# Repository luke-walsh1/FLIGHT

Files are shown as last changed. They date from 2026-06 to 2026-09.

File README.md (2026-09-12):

<p align="center">

</p>

## FLIGHT

FLIGHT is a custom, high-performance rocket flight computer designed around a Raspberry Pi Pico (RP2040) to track, log, and deploy parachutes using a servo.

## Disclaimer
### The provided code is tested and working with the hardware; however, the servo and arm button controls can be customized to suit your specific needs and are not implimented in the code:)

---

rasppico altimiter 1 7



---

## Features

* Core Processing: Raspberry Pi Pico running custom data-logging, and control scripts.

* Integrated Sensors (GY-91): Combines an IMU (accelerometer/gyroscope) to measure high-G launch forces (± 16g) and orientation, alongside a precision barometer (BMP280) to calculate real-time altitude changes.

* Recovery: Dedicated PWM outputs to trigger a servo mechanism for physical parachute deployment at apogee or however you wish to use it. not implimented in code, challange for yourself :)

* Power & Protection Circuitry: Integrated TP4056 LiPo charging network backed by a comprehensive safety protection block (DW01A controller + FS8205A dual-MOSFET switch) to safely manage battery current and prevent over-discharge.

* Voltage Regulation (MT3608): A  DC-DC boost converter circuit to cleanly step up battery power to a stable $5\text{V}$ line for the onboard servo control.

  rasppico altimiter 1 7 back



---

## Mechanical & Layout Design

* Developed on a dual-layer PCB with a massive Ground Plane optimized for low electrical noise and high signal integrity.
  
* Designed with wide, heavy-current traces ($0.8\text{mm} - 1.0\text{mm}$) on the critical power highway loops (+BATT and -BATT) to safely absorb massive amp spikes when the deployment servos actuate.
  
* Custom aerospace graphics and visual infographics directly on the silkscreen layer.

<p align="center">
 
</p>

# DATA

The goal is to log data. FLIGHT saves data in a format that looks like this:



---

These numbers by themselves arent that helpfull however with the help of a python program we can graph this data and mark the max altitude and other data points.

---



---

Included in the files is also a 3d printable bracket to mount flight to your rocket,
step file for your own needs.
M3 countersunk screw holes for mounting to rocket.

More on my YouTube and Stardance Profile:

https://stardance.hackclub.com/projects/18720

https://www.youtube.com/watch?v=rl3e3K6eBTs

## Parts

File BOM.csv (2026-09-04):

ALL CAPS AND RESISTORS ARE SMD 0805 SIZE
Capacitors |  | Rough price in usd
c1 | 0.1uf
c2 | 10uf
c3 | 47uf
c4 | 22uf
c5 | 22uf
c6 | 10uf
Resistors
R1 | 1K
R2 | 1K
R3 | 1K
R4 | 1K
R5 | 100 ohm
R6 | 16K
R7 | 2.2K
IC'S | Footprint
TP4056 | SOP8 | 1
FS8205A | SOP65P640X120-8N | This and dw01a for
DW01A | SOT-23-6 | 4.67
MT3608 | SOT-23-6 | 2
2.54mm PIN HEADERS
1x2 | 2 | Kit for 5.34
1x3 | 1
1x6 | 2
1x8 | 1
Diodes
SS34 | 1
0805 LED | 2
Inductors
22uH | 10x10x4
Connectors
jts tht 1x2 2.0mm horizontal |  | 4.74
other items
Raspberry Pi Pico |  | 6.6
Micro SD card breakout |  | 2
GY-91 Breakout |  | 10.6

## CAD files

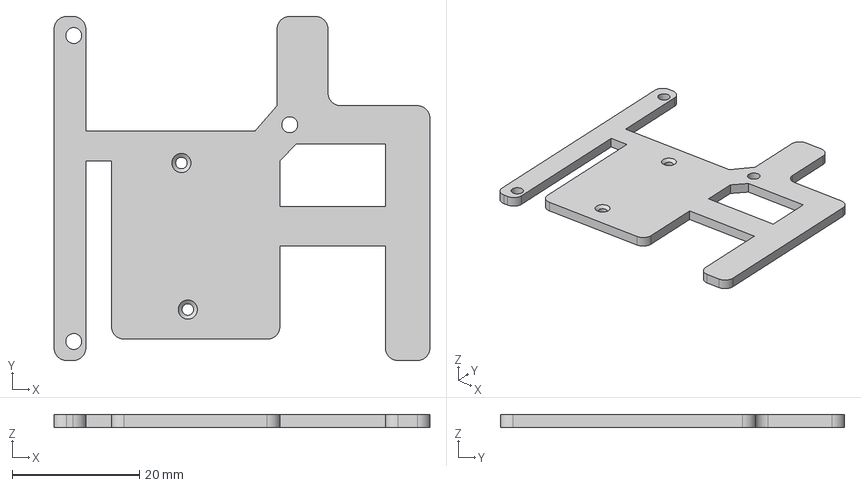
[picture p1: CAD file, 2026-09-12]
3D MODELS/MOUNT.step
59.0 x 54.0 x 2.00 mm

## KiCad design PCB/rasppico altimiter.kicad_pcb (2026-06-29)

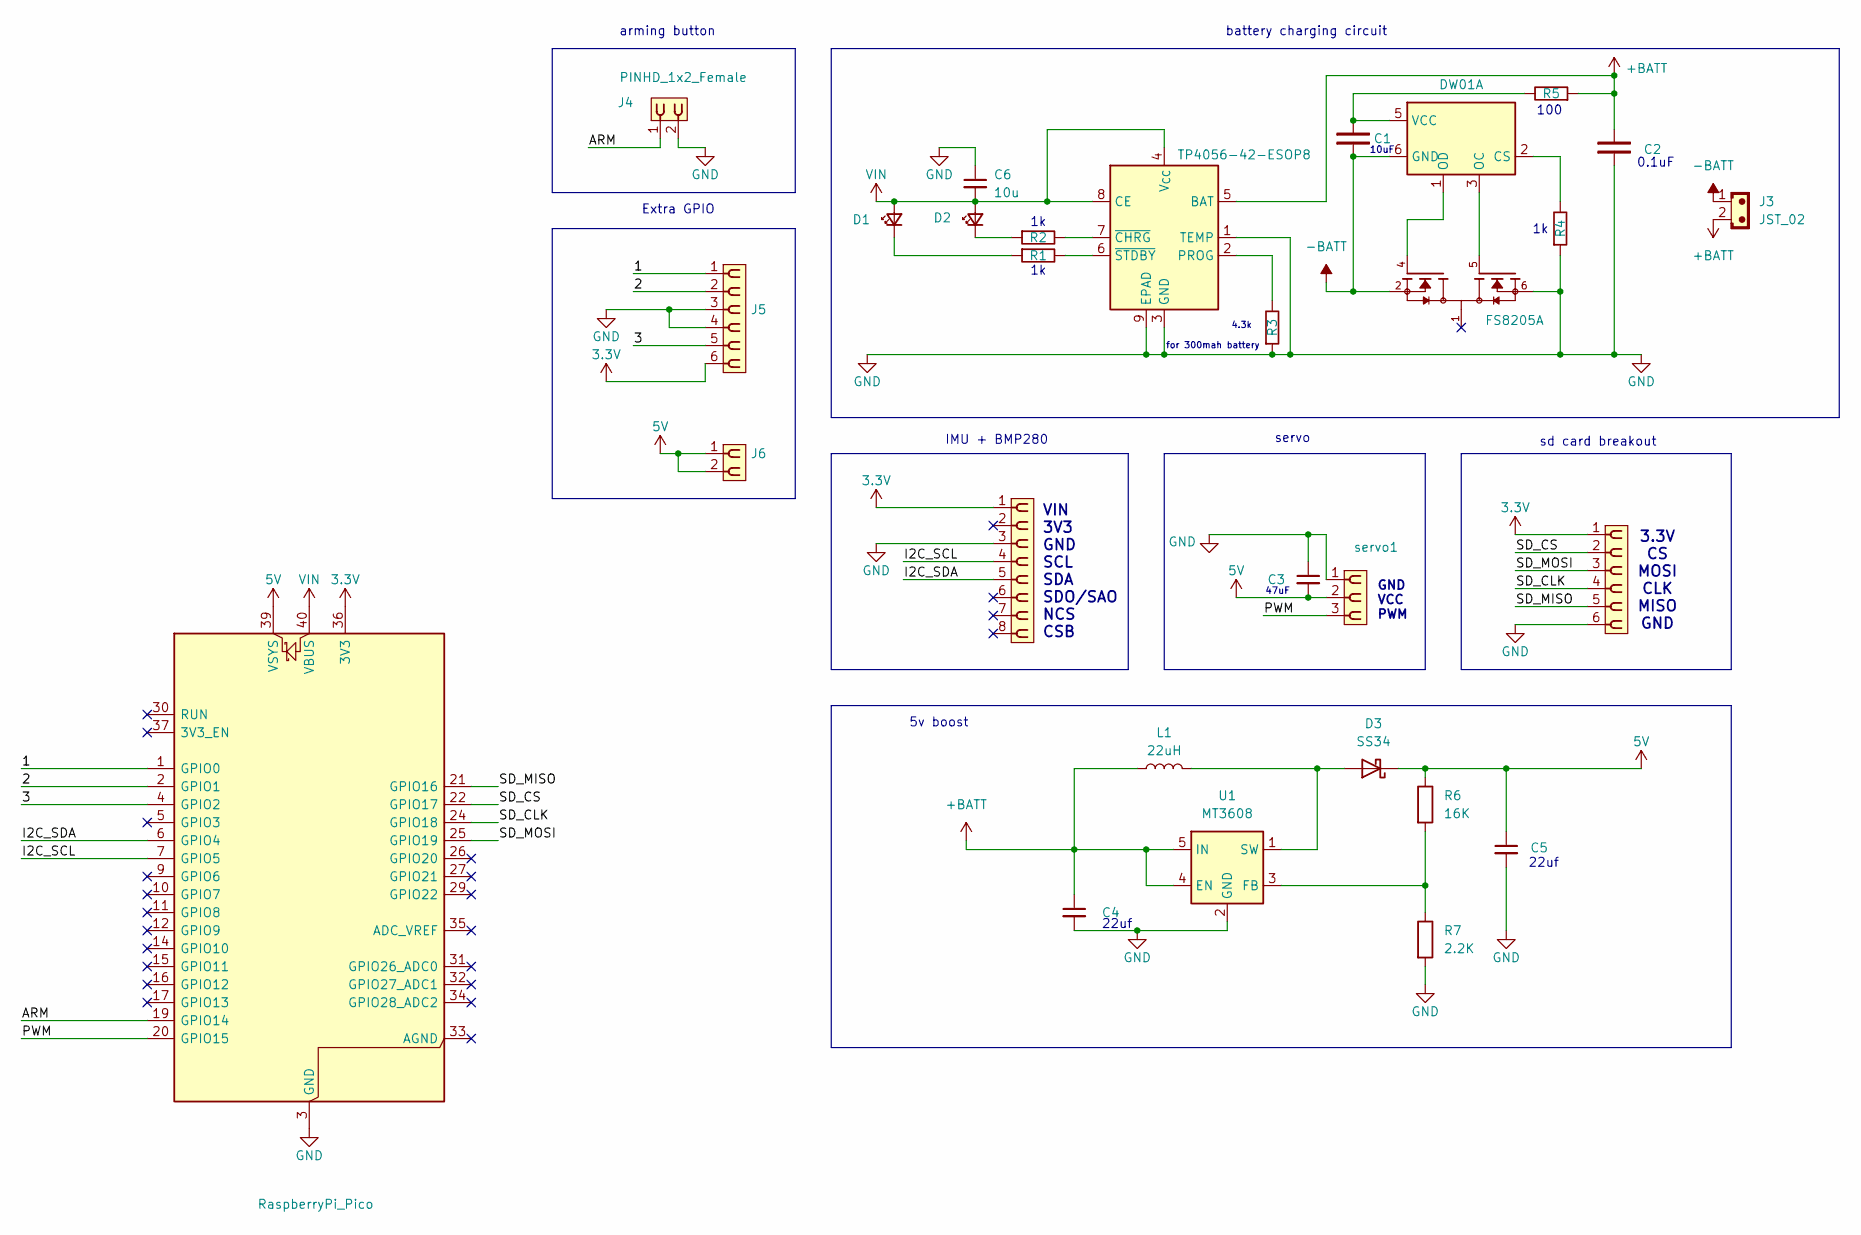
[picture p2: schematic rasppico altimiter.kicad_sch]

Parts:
A2: RaspberryPi_Pico; RaspberryPi_Pico_Common_Unspecified
C1, C2: Capacitor_NP; C_0805_2012Metric
C3, C4, C5: C; C_0805_2012Metric; Voltage 1kV; Tolerance 100%
C6: 10u; C_0603_1608Metric; Voltage 1kV; Tolerance 100%
D1, D2: LED; LED_0805_2012Metric
D3: SS34; D_SMA
J1, J5: PINHD_1x6_Female; PinSocket_1x06_P2.54mm_Vertical
J2: PINHD_1x8_Female; PinSocket_1x08_P2.54mm_Vertical
J3: JST_02; JST_PH_S2B-PH-K_1x02_P2.00mm_Horizontal
J4, J6: PINHD_1x2_Female; PinSocket_1x02_P2.54mm_Vertical
L1: 22uH; L_10.4x10.4_H4.8
Q1: FS8205A; SOP65P640X120-8N; PARTREV 1.7
R1, R2, R3, R4, R5: Resistor; R_0805_2012Metric
R6: 16K; R_0805_2012Metric
R7: 2.2K; R_0805_2012Metric
U1: MT3608; SOT-23-6
U4: TP4056-42-ESOP8; SOIC-8-1EP_3.9x4.9mm_P1.27mm_EP2.41x3.3mm_ThermalVias
U5: DW01A; SOT-23-6
servo1: PINHD_1x3_Female; PinSocket_1x03_P2.54mm_Vertical

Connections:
3.3V: A2.36 (3V3), J1.1, J2.1, J5.6
5V: A2.39 (VSYS), C3.2, C5.1, D3.1 (K), J6.1, J6.2, R6.1, servo1.2
+BATT: C2.2, C4.1, J3.2, L1.1, R5.1, U1.4 (EN), U1.5 (IN), U4.5 (BAT)
-BATT: C1.1, J3.1, Q1.2, Q1.3, U5.6 (GND)
/1: A2.1 (GPIO0), J5.1
/2: A2.2 (GPIO1), J5.2
/3: A2.4 (GPIO2), J5.5
/ARM: A2.19 (GPIO14), J4.1
/I2C_SCL: A2.7 (GPIO5), J2.4
/I2C_SDA: A2.6 (GPIO4), J2.5
/PWM: A2.20 (GPIO15), servo1.3
/SD_CLK: A2.24 (GPIO18), J1.4
/SD_CS: A2.22 (GPIO17), J1.2
/SD_MISO: A2.21 (GPIO16), J1.5
/SD_MOSI: A2.25 (GPIO19), J1.3
GND: A2.3 (GND), A2.8 (GND), A2.13 (GND), A2.18 (GND), A2.23 (GND), A2.28 (GND), A2.38 (GND), C2.1, C3.1, C4.2, C5.2, C6.1, J1.6, J2.3, J4.2, J5.3, J5.4, Q1.6, Q1.7, R3.1, R4.1, R7.2, U1.2 (GND), U4.1 (TEMP), U4.3 (GND), U4.9 (EPAD), servo1.1
unnamed: D1.1 (K), R1.1
unnamed: D2.1 (K), R2.1
unnamed: D3.2 (A), L1.2, U1.1 (SW)
unnamed: R6.2, R7.1, U1.3 (FB)
unnamed: R3.2, U4.2 (PROG)
unnamed: R2.2, U4.7 (~CHRG)
unnamed: R1.2, U4.6 (~STDBY)
unnamed: R4.2, U5.2 (CS)
unnamed: Q1.5, U5.3 (OC)
unnamed: Q1.4, U5.1 (OD)
unnamed: C1.2, R5.2, U5.5 (VCC)
VIN: A2.40 (VBUS), C6.2, D1.2 (A), D2.2 (A), U4.4 (V_{CC}), U4.8 (CE)

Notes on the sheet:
GND VCC PWM
Extra GPIO
22uf
100
battery charging circuit
VIN 3V3 GND SCL SDA SDO/SAO NCS CSB
sd card breakout
47uF
4.3k for 300mah battery
servo
0.1uF
5v boost
10uF
3.3V CS MOSI CLK MISO GND
IMU + BMP280
arming button

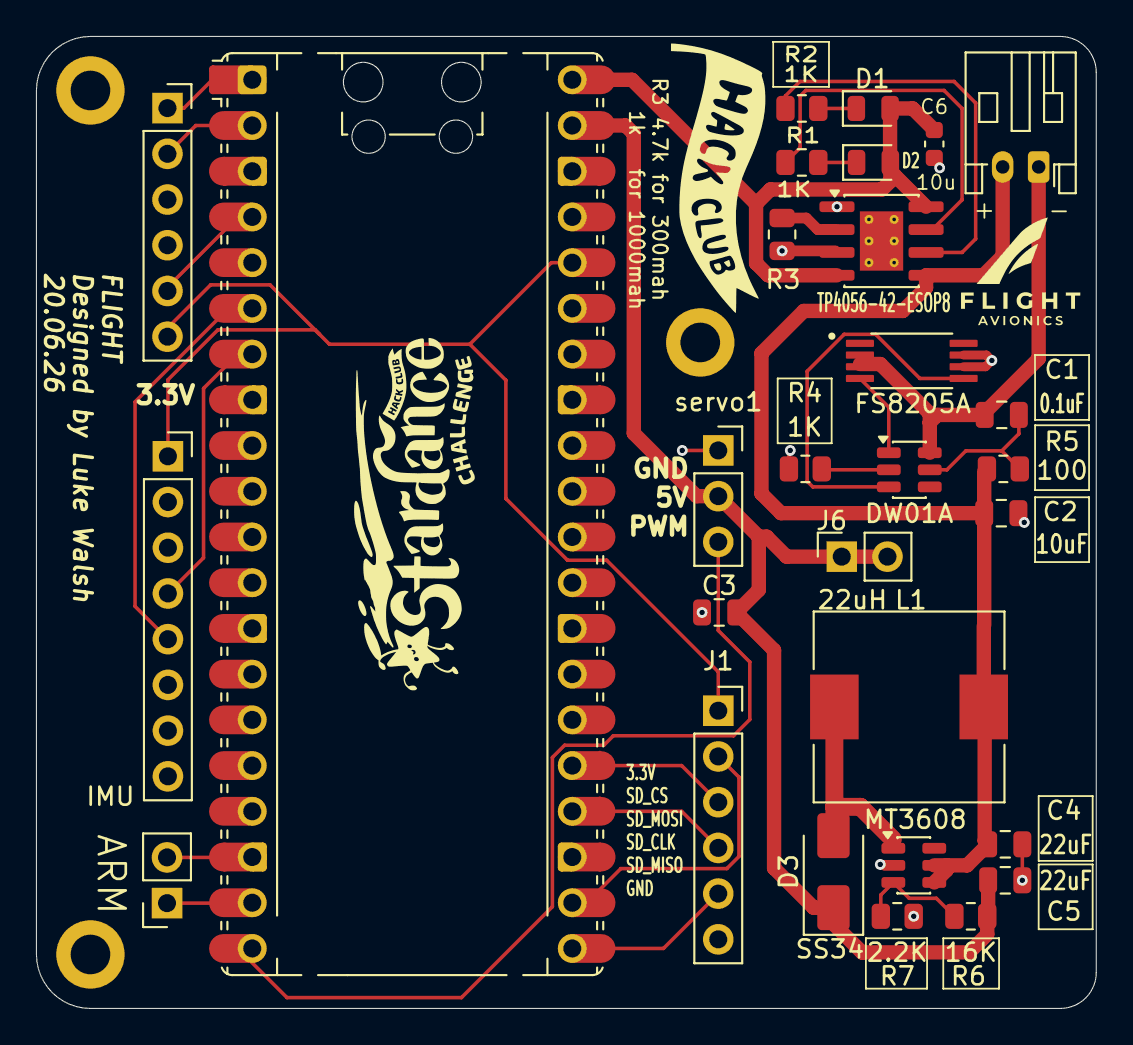
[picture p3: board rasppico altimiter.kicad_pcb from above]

Board: 2 copper layers, 58.9 x 54.0 mm, 29 parts (0 on the bottom side), 28 nets.

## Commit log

2026-06-20 Enhance README with detailed project specifications
    Expanded the README to include details about core processing, integrated sensors, actuation, power circuitry, and voltage regulation.
2026-06-24 Add flight core system code in FLIGHT_CODE.md
    This file contains the code for the flight core system, including hardware pin configuration, initialization, and active flight runtime logging.
2026-06-25 Add Bill of Materials (BOM) for project components
2026-06-25 Rename FINAL V1.7.rar to GERBER FILES V1.7.rar
2026-07-27 Add flight core payload system with logging
    This file implements a flight core payload system that reads temperature, pressure, and accelerometer data, logging it to a MicroSD card.
2026-08-07 Update disclaimer for code customization details
    Clarified the disclaimer regarding code customization for servo and arm button controls.
2026-09-04 Add files via upload
    added new bom with prices
    [Untitled spreadsheet - Sheet1.csv]
2026-09-04 Add bill of materials spreadsheet
2026-09-04 Update README with 3D printable bracket details
    Added information about included 3D printable bracket and customization files.
2026-09-12 Rename GERBER FILES V1.7.rar to PCB/GERBER FILES V1.7.rar
2026-09-12 Rename rasppico altimiter.kicad_pro to PCB/rasppico altimiter.kicad_pro
2026-09-12 Rename rasppico altimiter.kicad_pcb to PCB/rasppico altimiter.kicad_pcb
    [rasppico altimiter.kicad_pcb]
2026-09-12 Rename rasppico altimiter.kicad_sch to PCB/rasppico altimiter.kicad_sch
    [rasppico altimiter.kicad_sch]
2026-09-12 Rename MOUNT.step to 3D MODELS/MOUNT.step
    [MOUNT.step]
2026-09-12 Clarify file types and mounting instructions in README
    Updated README to clarify file types and mounting details.
